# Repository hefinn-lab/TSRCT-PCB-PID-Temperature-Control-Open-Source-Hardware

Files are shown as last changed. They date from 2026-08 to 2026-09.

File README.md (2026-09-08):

# An Open-Source Dual-Channel RTD Thermal-Control Platform for Research-Scale PEM Water Electrolysis Balance-of-Plant Integration

**TSRCT-PCB-01** is an Arduino Nano Every–based temperature-control board for experimental thermal management. It connects two Pt100 or Pt1000 resistance temperature detectors (RTDs) to independent **5 V digital solid-state-relay (SSR) control outputs**, with controller power and host communication through a single USB connection. External SSRs switch a separately powered heater circuit.

**Repository release: v1.1.1 | Firmware and Python tools: V1.1**

[Setup and dependencies](DEPENDENCIES.md) · [Release notes](RELEASE-NOTES.md) · [Citation](CITATION.cff) · [Licensing](LICENSE.md)

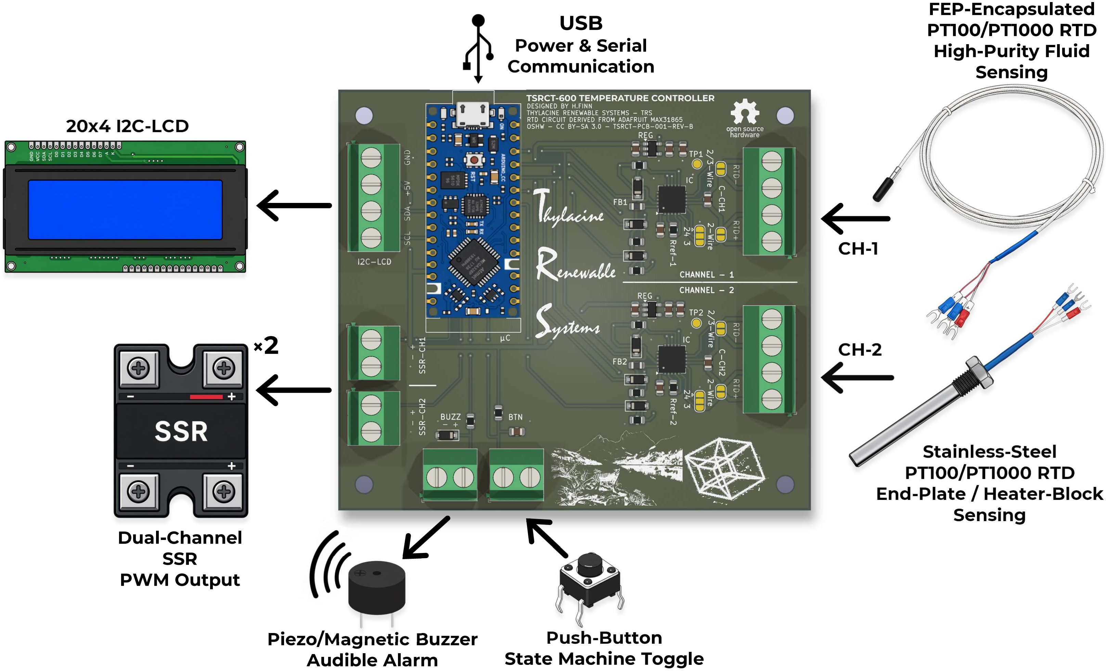
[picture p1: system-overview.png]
TSRCT-PCB-01 system overview showing dual RTD inputs, SSR outputs, USB communication and user-interface connections


The accompanying manuscript describes the circuit, analytical tuning methods, experimental results, and operating scope. The reported experiments characterise temperature control on isolated, dry electrolysis-cell end plates.

## Basic functions

- Two MAX31865 RTD acquisition channels with independent temperature set points.
- Pt100 or Pt1000 operation, with matching component population and firmware settings; configurable 2-, 3-, or 4-wire connections.
- PI/PID control, manual operation, set-point ramping, and anti-windup.
- Windowed SSR actuation, with nominal 1 s control and actuation windows.
- Open-loop step-response acquisition and FOPDT-based analytical SIMC PI / iSIMC PID tuning tools.
- USB serial telemetry and companion Python logging and analysis.
- RTD fault handling, stale-measurement detection, and over-temperature alarms that disable both heater commands.
- Connections for an I²C display, push button, and audible alarm.

## Adafruit design attribution and changes

**The RTD front ends are based on the Adafruit MAX31865 breakout design by Limor Fried/Ladyada for Adafruit Industries.** The MAX31865 interface software is derived from Adafruit's Arduino library. The original projects are:

- [Adafruit MAX31865 hardware: schematics and PCB files](https://github.com/adafruit/Adafruit-MAX31865-PCB)
- [Adafruit MAX31865 Arduino library](https://github.com/adafruit/Adafruit_MAX31865)

**Hardware changes:** TSRCT-PCB-01 integrates two RTD front ends into one control PCB with the Nano Every, SSR command connections, and display, button, and alarm interfaces. The layout consolidates the measurement and control wiring while retaining configurable RTD connections. Reference resistors and input-filter capacitors are populated for the selected sensor type.

**Firmware changes:** RTD acquisition has been changed to a **non-blocking state machine**. Bias settling, conversion waiting, and readout are scheduled as separate stages so acquisition does not hold up the main loop during the sensor waiting periods. The application adds independent control loops, timer-scheduled SSR windows, analytical tuning support, fault handling, and host telemetry. The V1.1 timer implementation uses the Nano Every's ATmega4809 TCB2 peripheral; another microcontroller requires timer adaptation.

## RTD wiring and soldering

Use the Adafruit learning guide for the underlying RTD connection principles and solder-jumper configuration:

- [MAX31865 guide: overview](https://learn.adafruit.com/adafruit-max31865-rtd-pt100-amplifier/)
- [Assembly and soldering guide](https://learn.adafruit.com/adafruit-max31865-rtd-pt100-amplifier/assembly)
- [RTD wiring and configuration: 2-, 3-, and 4-wire sensors](https://learn.adafruit.com/adafruit-max31865-rtd-pt100-amplifier/rtd-wiring-config)

These instructions illustrate the Adafruit breakout. Use the **TSRCT-PCB-01 schematic and PCB labels** to identify the corresponding terminals and jumpers before soldering or cutting a trace.

| Sensor | Nominal resistance at 0 °C | Reference resistor | RTD input-filter capacitor |
| --- | ---: | ---: | ---: |
| Pt100 | 100 Ω | 430 Ω | 100 nF |
| Pt1000 | 1000 Ω | 4.3 kΩ | 10 nF |

Set the firmware's nominal RTD resistance, reference-resistor value, and wiring mode to match each populated channel. Changing from Pt100 to Pt1000 requires matching hardware and software configuration. The V1.1 default configuration uses two three-wire Pt100 sensors with 430 Ω reference resistors.

## Getting started

1. Assemble the board using its schematic and bill of materials, then configure the RTD connections as above.
2. Follow [DEPENDENCIES.md](DEPENDENCIES.md) to configure the Arduino Nano Every target and Arduino megaAVR Boards core, install the Python packages, and select the matching sketch/logger pair.
3. Connect the RTDs and compatible SSR control inputs, checking input-current requirements against the board's output capability. Heater power must pass through the external switching circuit, with independent thermal protection.
4. Upload the nominal-control or analytical-tuning sketch and run its companion Python logger. Before enabling heater power, confirm plausible temperature readings, correct sensor-to-heater channel pairing, and heater-off behaviour on your assembled system.

The loggers record telemetry; closing a logger does not stop heating. Use the controller's local control/abort function. Repository documentation can receive a new release version while unchanged firmware and Python tools retain V1.1.

## Attribution and licensing

Hardware design files are licensed under **CC BY-SA 3.0**. Original TSRCT software contributions are licensed under **MIT**, and Adafruit-derived code retains its upstream notices. See [LICENSE.md](LICENSE.md) for the component-specific terms and [ADAFRUIT-NOTICES.md](ADAFRUIT-NOTICES.md) for attribution. Preserve the applicable notices when redistributing or modifying the design or software.

Please acknowledge the original Adafruit projects when reusing these RTD front ends or their interface code, and refer to the accompanying manuscript for the TSRCT-PCB-01 design and experimental methods.

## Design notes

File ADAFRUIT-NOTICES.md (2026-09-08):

# Adafruit attribution and upstream notices

## Hardware

The TSRCT-PCB-01 RTD front ends are adapted from the **Adafruit MAX31865 PCB**, designed by **Limor Fried/Ladyada for Adafruit Industries**.

- [Original hardware repository](https://github.com/adafruit/Adafruit-MAX31865-PCB)
- [Upstream CC BY-SA 3.0 licence](https://github.com/adafruit/Adafruit-MAX31865-PCB/blob/master/license.txt)
- [Assembly and wiring guide](https://learn.adafruit.com/adafruit-max31865-rtd-pt100-amplifier/)

Changes in TSRCT-PCB-01 include integrating two RTD front ends with an Arduino Nano Every, independent SSR command connections, and user-interface circuitry on one PCB. Hardware adaptations are distributed under CC BY-SA 3.0. See LICENSE-CC-BY-SA-3.0.txt for the legal text.

The following upstream README text is retained for attribution (its descriptions concern the original Adafruit breakout):

> Adafruit MAX31865 PCB
>
> Click here to purchase one from the Adafruit shop
>
> PCB files for the Adafruit MAX31865 RTD Sensor Breakout. Format is EagleCAD schematic and board layout
>
> https://www.adafruit.com/product/3328
>
> Description
>
> For precision temperature sensing, nothing beats a Platinum RTD. Resistance temperature detectors (RTDs) are temperature sensors that contain a resistor that changes resistance value as its temperature changes, basically a kind of thermistor. In this sensor, the resistor is actually a small strip of Platinum with a resistance of 100 ohms at 0°C, thus the name PT100.
>
> Compared to most NTC/PTC thermistors, the PT type of RTD is much most stable and precise (but also more expensive) PT100's have been used for many years to measure temperature in laboratory and industrial processes, and have developed a reputation for accuracy (better than thermocouples), repeatability, and stability.
>
> However, to get that precision and accuracy out of your PT100 RTD you must use an amplifier that is designed to read the low resistance. Better yet, have an amplifier that can automatically adjust and compensate for the resistance of the connecting wires. If you're looking for a great RTD sensor, today is your lucky day because we have a lovely Adafruit RTD Sensor Amplifier with the MAX31865 breakout for use with any 2, 3 or 4 wire PT100 RTD!
>
> License
>
> Adafruit invests time and resources providing this open source design, please support Adafruit and open-source hardware by purchasing products from Adafruit!
>
> Designed by Limor Fried/Ladyada for Adafruit Industries.
>
> Creative Commons Attribution/Share-Alike, all text above must be included in any redistribution. See license.txt for additional details.

## Software

The local MAX31865 interface and temperature-conversion routines in the V1.1 sketches are derived from the **Adafruit MAX31865 Arduino library**, written by **Limor Fried/Ladyada for Adafruit Industries**.

- [Original software repository](https://github.com/adafruit/Adafruit_MAX31865)
- [Source file carrying the upstream notice](https://github.com/adafruit/Adafruit_MAX31865/blob/master/Adafruit_MAX31865.cpp)

The upstream source banner is preserved below. Retain this banner in redistributed source files containing the derived driver:

```cpp
/***************************************************
  This is a library for the Adafruit PT100/P1000 RTD Sensor w/MAX31865

  Designed specifically to work with the Adafruit RTD Sensor
  ----> https://www.adafruit.com/products/3328

  This sensor uses SPI to communicate, 4 pins are required to
  interface

  Adafruit invests time and resources providing this open source code,
  please support Adafruit and open-source hardware by purchasing
  products from Adafruit!

  Written by Limor Fried/Ladyada for Adafruit Industries.
  BSD license, all text above must be included in any redistribution
 ****************************************************/
```

The upstream README also states:

> Adafruit MAX31865
>
> This is the Adafruit MAX31865 Arduino Library
>
> Tested and works great with the Adafruit Thermocouple Breakout w/MAX31865
>
> http://www.adafruit.com/products/3328
>
> These sensors use SPI to communicate, 4 pins are required to interface
>
> Adafruit invests time and resources providing this open source code, please support Adafruit and open-source hardware by purchasing products from Adafruit!
>
> Written by Limor Fried/Ladyada for Adafruit Industries.
>
> BSD license, check license.txt for more information All text above must be included in any redistribution

TSRCT modifications separate bias settling, conversion waiting, and readout into a non-blocking acquisition sequence, and integrate acquisition with dual-channel control, timer-based actuation, fault supervision, and telemetry. Original TSRCT contributions are MIT-licensed; the upstream portions retain the notices above.

The upstream software identifies its licence as **BSD** in the notices reproduced above. Preserve these notices, together with any additional licence text accompanying the incorporated source version. The MIT licence for original TSRCT contributions does not replace the upstream terms.

Adafruit is credited for its original contributions; this attribution does not imply endorsement of TSRCT-PCB-01.

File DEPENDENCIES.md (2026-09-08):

# Dependencies and running the V1.1 tools

This document describes the dependencies and execution instructions
for the V1.1 firmware and companion Python tools distributed with
repository release v1.1.1.

## Firmware

- Board: **Arduino Nano Every (ATmega4809)**, using **Arduino megaAVR Boards** in Boards Manager. A classic ATmega328P Nano is not compatible with the direct TCB2 timer implementation.
- LCD library: **LiquidCrystal_I2C**, using the Frank de Brabander **1.1.2 API** (`init()` and `backlight()`). Select the matching implementation; libraries sharing this header name can expose different APIs.
- `Arduino.h`, `Wire.h`, `SPI.h`, AVR interrupt/watchdog headers, and standard C headers come with the selected board toolchain.
- The modified MAX31865 driver is defined locally in both sketches. **No separate Adafruit_MAX31865, Adafruit BusIO, or PID library is required by these files.** Adafruit attribution remains required for the incorporated code.

## Matched files

| Task | Arduino sketch | Python companion |
| --- | --- | --- |
| Nominal control | `V1.1_TSRCT_PCB_Nominal_Dual_Channel.ino` | `V1.1_TSRCT_PCB_Nominal_Logger.py` |
| Open-loop identification and analytical tuning | `Analytical-Tuning-uC-Firmware-V1.1.ino` | `Analytical-Tuning-Logger.py` |

Use the filenames above when selecting the firmware and companion logger. Open each `.ino` in Arduino IDE and accept its prompt to create a matching sketch folder if needed. Upload only the sketch for the desired task. Before enabling heater power, check sensor configuration, channel pairing, and heater-off behaviour on the assembled system.

## Python

Use **Python 3.9 or newer**. From the repository root, create a virtual environment and install the dependencies:

```bash
python -m venv .venv
```

Activate it on Windows PowerShell:

```powershell
.venv\Scripts\Activate.ps1
```

Or on macOS/Linux:

```bash
source .venv/bin/activate
```

Then install:

```bash
python -m pip install -r requirements.txt
```

| Tool | External packages |
| --- | --- |
| Nominal logger | `pyserial`, `openpyxl` |
| Analytical logger | `pyserial`, `numpy`, `pandas`, `matplotlib`, `openpyxl`, `Pillow` |
| Optional analytical nonlinear fit | `scipy` |

Pillow is used by workbook image embedding. SciPy is optional; without it the primary crossing-based FOPDT identification and analytical tuning remain available.

```bash
python -m pip install -r requirements-optional.txt
```

To record the package versions used for your experiments:

```bash
python --version
python -m pip freeze > requirements-tested.txt
```

## Run

Close Arduino Serial Monitor and replace the example port with the board's port. Run from the directory containing the chosen logger, or supply its path.

```bash
python V1.1_TSRCT_PCB_Nominal_Logger.py --port COM4
python Analytical-Tuning-Logger.py --port COM5
```

On Linux, a port may be `/dev/ttyACM0`; on macOS, use the actual `/dev/cu.*` device.

Both pairs use **115200 baud**. The loggers are passive: they record and analyse telemetry rather than command heater shutdown. Closing a logger does not stop heating; use the board's local control/abort function.

For offline reconstruction:

```bash
python V1.1_TSRCT_PCB_Nominal_Logger.py --rebuild capture.csv
python Analytical-Tuning-Logger.py --rebuild capture.csv --controller isimc-pid
```

The analytical logger exports a selected channel's gains; apply the exported settings to the corresponding nominal-firmware channel. Default hardware settings in the V1.1 sketches are three-wire Pt100, 430 ohm reference conversion, and 50 Hz rejection.

Hardware design editing uses KiCad 10 as identified in the manuscript; KiCad is not needed to run the firmware or loggers.

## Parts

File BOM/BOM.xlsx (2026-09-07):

Qty | Digi-Key Part Number | Manufacturer Part Number | Manufacturer | Customer Reference | Designation | Footprint | Notes
1 |  | ABX00033 | Arduino | μC | Arduino Nano Every | Arduino Nano Every_Nano
2 | MAX31865ATP+-ND | MAX31865ATP+ | Analog Devices | U1, U4 (IC) | MAX31865 | Package_DFN_QFN:QFN-20-1EP_5x5mm_P0.65mm_EP3.1x3.1mm_ThermalVias | TQFN-20 5x5mm -- verified
2 | 576-2980-1-ND | MIC5225-3.3YM5-TR | Microchip | U2, U3 (REGULATOR) | MIC5225-3.3 | Package_TO_SOT_SMD:SOT-23-5 | SOT-23-5 -- verified
7 | 31-1N4148W-7-F-WCT-ND | 1N4148W-7-F-W | Diodes Inc. | D1–D7 | 1N4148 | Diode_SMD:D_SOD-123 | SOD-123 verified (NOT SOD-323). -W variant in stock
2 | 490-1054-1-ND | BLM21PG221SN1D | Murata | FB1, FB2 | Ferrite 220Ω @ 100MHz | Inductor_SMD:L_0805_2012Metric | 0805 verified
VAR. | P430DACT-ND | ERA-6AEB431V | Panasonic | Rref - PT100 channels | 430Ω 0.1% thin-film | Resistor_SMD:R_0805_2012Metric | 0805 verified - Rref for PT100 channels. Populate one per PT100 channel
VAR. | P4.3KDACT-ND | ERA-6AEB432V | Panasonic | Rref - PT1000 channel | 4.3kΩ 0.1% thin-film | Resistor_SMD:R_0805_2012Metric | 0805 verified - Rref for Pt1000 channels. Populate one per PT1000 channel
7 | 311-10.0KCRCT-ND | RC0805FR-0710KL | Yageo | R2, R3, R4, R6, R7, R8, R9 | 10K 1% | Resistor_SMD:R_0805_2012Metric | 0805 verified
1 | 311-220CRCT-ND | RC0805FR-07220RL | Yageo | R10 | 220Ω 1% | Resistor_SMD:R_0805_2012Metric | 0805 verified
4 | 1276-1003-1-ND | CL21B104KBCNNNC | Samsung | C1, C2, C8, C9 | 0.1uF X7R 50V | Capacitor_SMD:C_0805_2012Metric | 0805 verified. Combined: 8× decoupling
VAR. | 1276-1003-1-ND | CL21B104KBCNNNC | Samsung | C-CH1/CH-2 for PT100 - 1x per channel | 0.1uF X7R 50V | Capacitor_SMD:C_0805_2012Metric | PT100 channel filter. Placed as C-CH1/C-CH2. Populate one per PT100 channel
4 | 1276-6454-1-ND | CL21A106KAYNNNG | Samsung | C4, C5, C11, C13 | 10uF X5R 25V | Capacitor_SMD:C_0805_2012Metric | 0805 verified. G-variant of original E-variant (out of stock); identical electrical spec.
1 | 1276-1029-1-ND | CL21B105KBFNNNE | Samsung | C6 | 1uF X7R 50V | Capacitor_SMD:C_0805_2012Metric | 0805 verified. Button debounce.
VAR. | 1276-1015-1-ND | CL21B103KBANNNC | Samsung | C-CH1/CH-2 for PT1000 - 1x per channel | 10nF X7R 50V | Capacitor_SMD:C_0805_2012Metric | PT1000 channel filter. Placed as C-CH1/C-CH2. Populate one per PT1000 channel
3 | 277-1265-ND | 1715747 | Phoenix Contact | J6, J7, I2C-LCD | Screw_Terminal_01x04 5.08mm | TerminalBlock_Phoenix:TerminalBlock_Phoenix_MKDS-1,5-4-5.08_1x04_P5.08mm_Horizontal | MKDS 1,5/4-5,08 — 4-pos 5.08mm verified
4 | 277-1263-ND | 1715721 | Phoenix Contact | SSR-CH1, SSR-CH2, BTN, BUZZ | Screw_Terminal_01x02 5.08mm | TerminalBlock_Phoenix:TerminalBlock_Phoenix_MKDS-1,5-2-5.08_1x02_P5.08mm_Horizontal | Out of stock -- alternative option fine otherwise order from Mouser with split order fine?
 | BOM Note: All quantities are for one assembled TSRCT-PCB-001 PCB unless otherwise stated. Red rows are RTD-configuration-dependent components; populate the appropriate values for the selected PT100/PT1000 channel configuration.

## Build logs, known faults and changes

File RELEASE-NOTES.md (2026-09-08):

# TSRCT-PCB-01 v1.1.1

Public release of TSRCT-PCB-01, an open-source dual-channel Pt100/Pt1000 PID temperature-control platform for Arduino Nano Every, developed for research-scale PEM water electrolysis thermal management.

Repository release **v1.1.1** packages firmware and companion Python tools **V1.1**.

This release brings together:

- Hardware design and fabrication files, bill of materials, and assembly documentation.
- Dual-channel nominal-control firmware with non-blocking MAX31865 acquisition, 5 V SSR commands, PI/PID control, and fault handling.
- Open-loop step-identification firmware and Python tools for FOPDT identification and SIMC PI / iSIMC PID tuning.
- Python serial logging with CSV and XLSX output.
- Dependency instructions, citation metadata, and component-specific licensing and Adafruit attribution.

The RTD front ends are adapted from Adafruit's MAX31865 hardware design. The incorporated Adafruit-derived interface code has been restructured for non-blocking acquisition.

Hardware: CC BY-SA 3.0. Original software: MIT. Adafruit-derived software retains its upstream BSD notice; see [LICENSE.md](LICENSE.md) and [ADAFRUIT-NOTICES.md](ADAFRUIT-NOTICES.md).

See [DEPENDENCIES.md](DEPENDENCIES.md) for the supported board, matched firmware/logger pairs, and setup. The accompanying manuscript describes the experimental performance on isolated, dry end plates. Before enabling heating, adopters should confirm operation on their assembled hardware using the checks in the [README](README.md).

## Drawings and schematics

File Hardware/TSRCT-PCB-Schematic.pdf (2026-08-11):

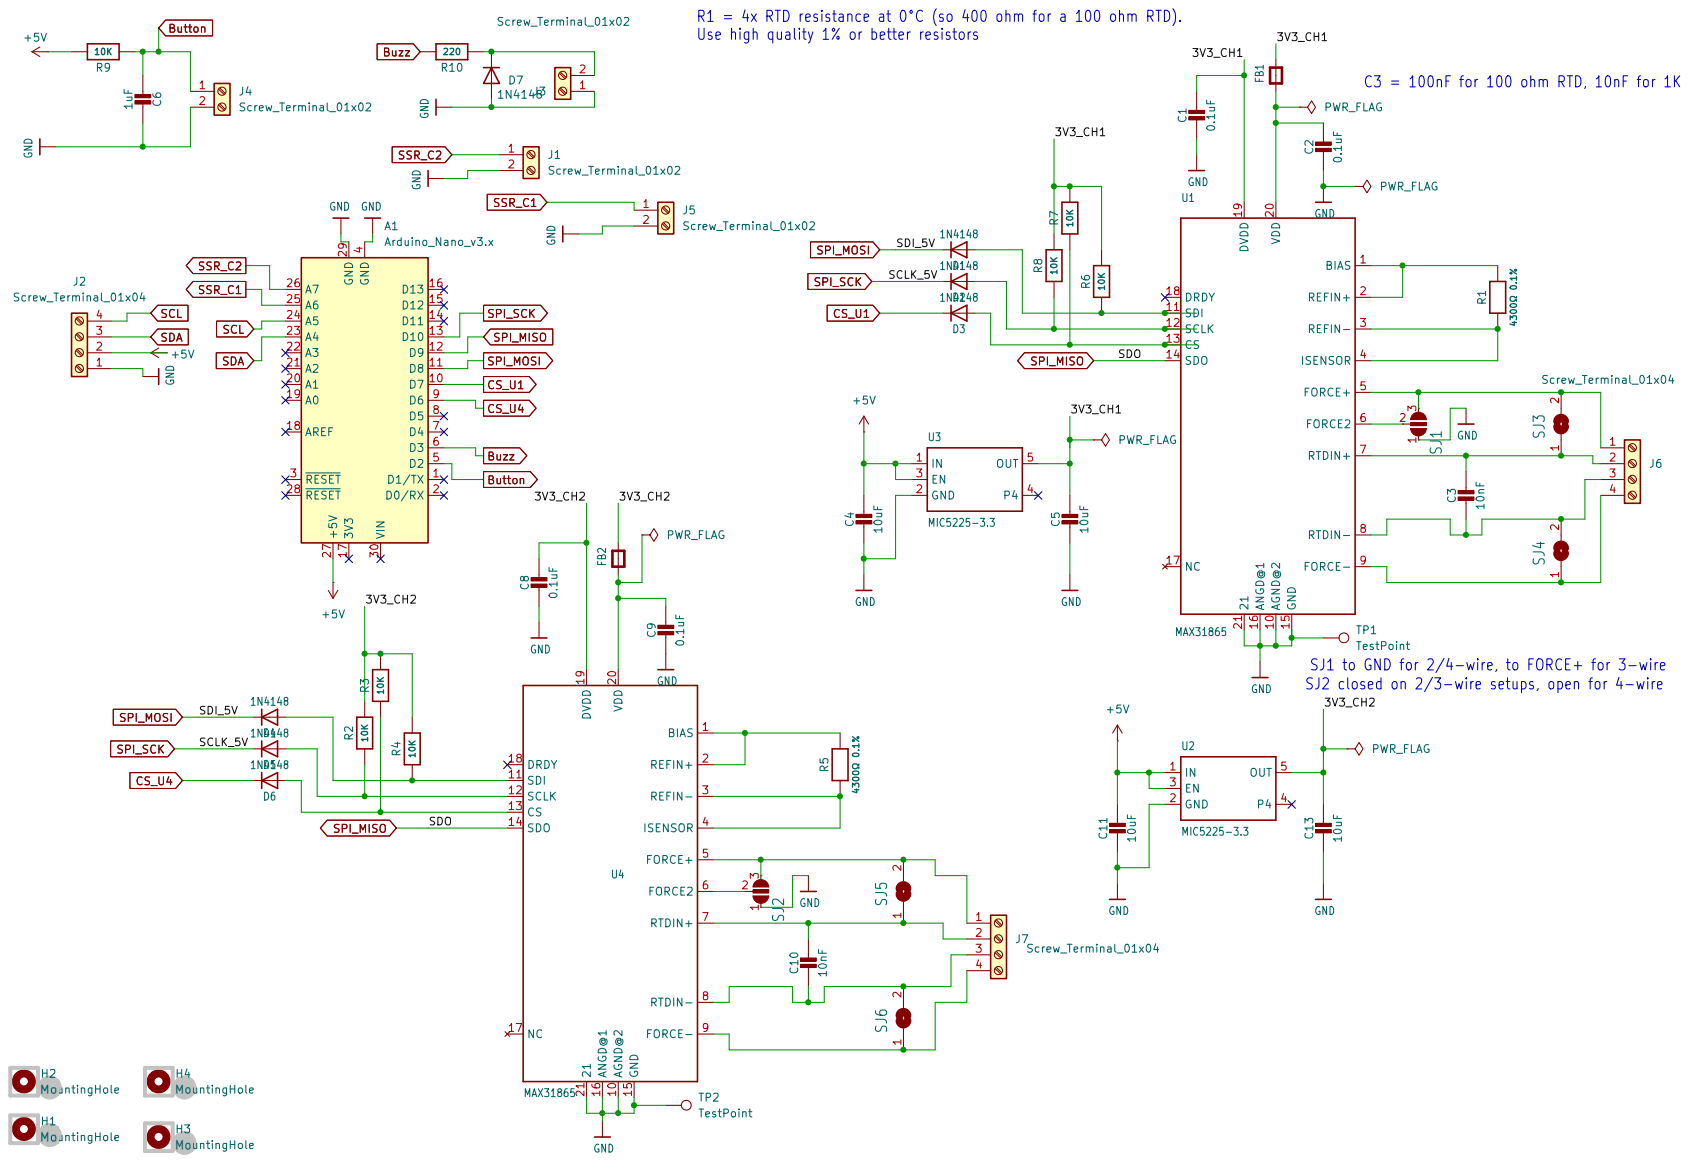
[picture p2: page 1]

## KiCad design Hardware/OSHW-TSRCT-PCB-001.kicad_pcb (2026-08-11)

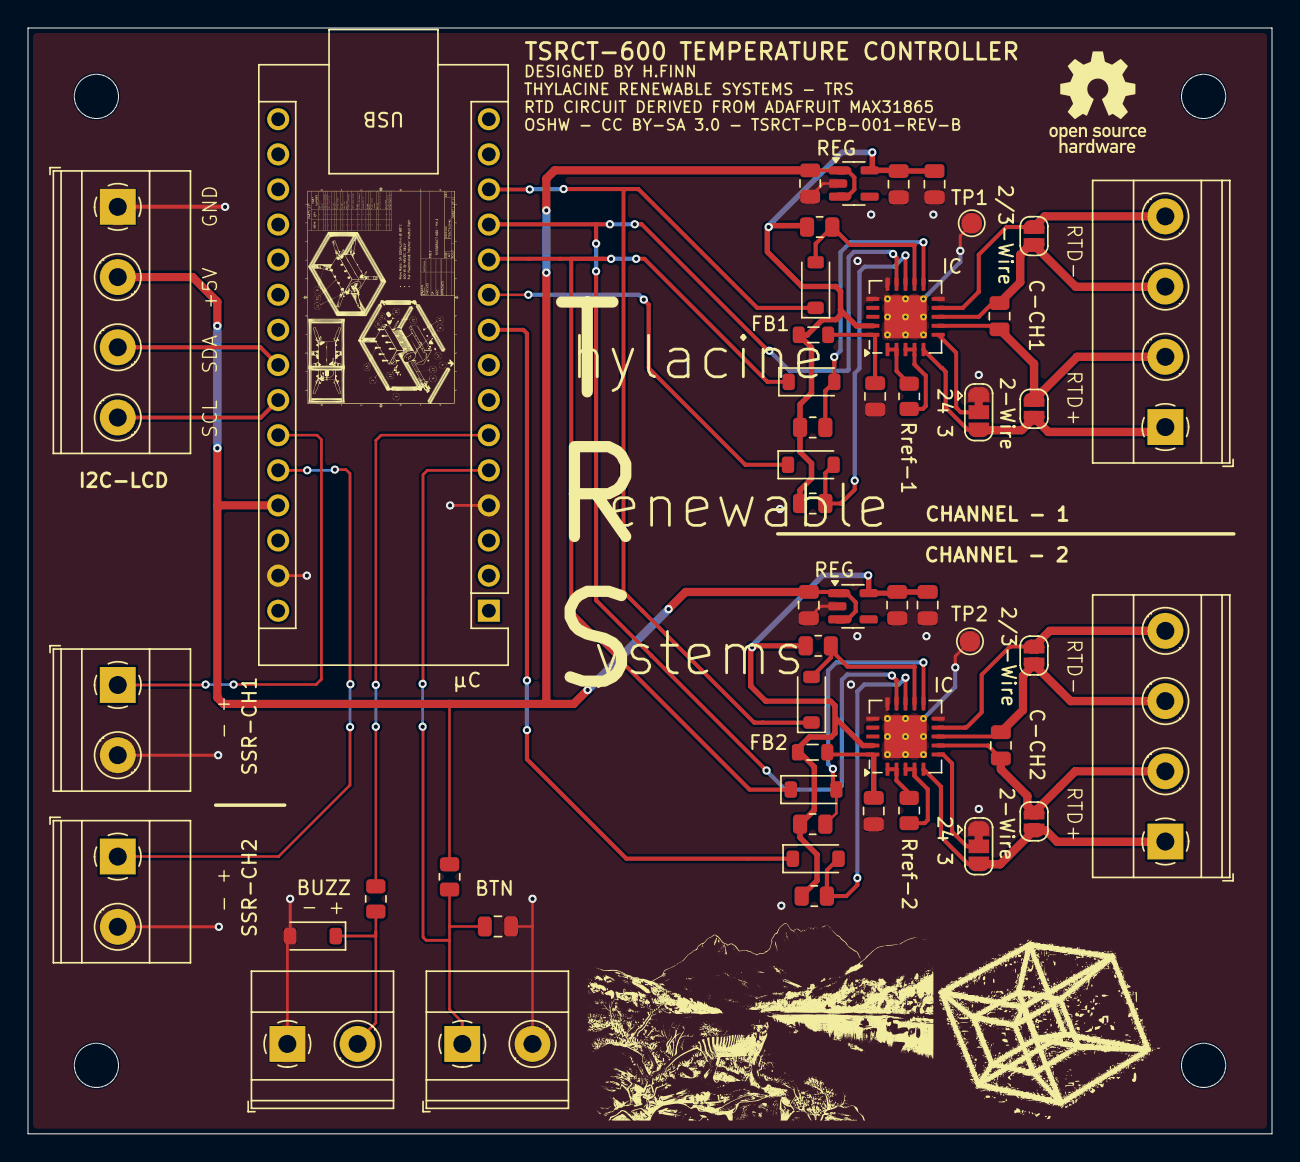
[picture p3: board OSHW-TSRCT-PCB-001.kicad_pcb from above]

Board: 2 copper layers, 90.0 x 80.0 mm, 54 parts (0 on the bottom side), 38 nets.

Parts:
2-Wire, 2-Wire#2, 2/3-Wire, 2/3-Wire#2: SOLDERJUMPER; SolderJumper-2_P1.3mm_Open_RoundedPad1.0x1.5mm
24 3, 24 3#2: SOLDERJUMPER_2WAY; SolderJumper-3_P1.3mm_Bridged12_RoundedPad1.0x1.5mm
BTN: Screw_Terminal_01x02; TerminalBlock_Phoenix_MKDS-1,5-2-5.08_1x02_P5.08mm_Horizont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
BUZZ: Screw_Terminal_01x02; TerminalBlock_Phoenix_MKDS-1,5-2-5.08_1x02_P5.08mm_Horizont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
C1, C2, C8, C9: 0.1uF; C_0805_2012Metric
C4, C5, C11, C13: 10uF; C_0805_2012Metric
C6: 1uF; C_0805_2012Metric
C-CH1, C-CH2: 10nF; C_0805_2012Metric
D1, D2, D3, D4, D5, D6, D7: 1N4148; D_SOD-123
FB1, FB2: FERRITE-0805NO; L_0805_2012Metric
H1, H2, H3, H4: MountingHole; MountingHole_3.2mm_M3
I2C-LCD: Screw_Terminal_01x04; TerminalBlock_Phoenix_MKDS-1,5-4-5.08_1x04_P5.08mm_Horizont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
IC: MAX31865; TQFN-20-1EP_5x5mm_P0.65mm_EP3.1x3.1mm_ThermalVias
IC#2: MAX31865; TQFN-20-1EP_5x5mm_P0.65mm_EP3.1x3.1mm_ThermalVias
J6, J7: Screw_Terminal_01x04; TerminalBlock_Phoenix_MKDS-1,5-4-5.08_1x04_P5.08mm_Horizont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
R2, R3, R4, R6, R7, R8, R9: 10K; R_0805_2012Metric
R10: 220; R_0805_2012Metric
REG: MIC5225-3.3; SOT-23-5
REG#2: MIC5225-3.3; SOT-23-5
Rref-1, Rref-2: 4300Ω 0.1%; R_0805_2012Metric
SSR-CH1, SSR-CH2: Screw_Terminal_01x02; TerminalBlock_Phoenix_MKDS-1,5-2-5.08_1x02_P5.08mm_Horizont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
TP1, TP2: TestPoint; TestPoint_Pad_D1.5mm
μC: Arduino_Nano_v3.x; Arduino_Nano

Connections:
+5V: C4.1, C11.1, I2C-LCD.2, R9.2, REG.1 (IN), REG.3 (EN), REG#2.1 (IN), REG#2.3 (EN), μC.27 (+5V)
/3V3_CH1: C1.1, C5.1, FB1.2, IC#2.19 (DVDD), R6.2, R7.2, R8.2, REG.5 (OUT)
/3V3_CH2: C8.1, C13.1, FB2.2, IC.19 (DVDD), R2.2, R3.2, R4.2, REG#2.5 (OUT)
Button: BTN.1, C6.2, R9.1, μC.5 (D2)
Buzz: R10.2, μC.6 (D3)
CS_U1: D3.1, μC.10 (D7)
CS_U4: D6.1, μC.9 (D6)
GND: 24 3.1, 24 3#2.1, BTN.2, BUZZ.1, C1.2, C2.2, C4.2, C5.2, C6.1, C8.2, C9.2, C11.2, C13.2, D7.2 (A), I2C-LCD.1, IC.10 (AGND@2), IC.15 (GND), IC.16 (ANGD@1), IC.21, IC#2.10 (AGND@2), IC#2.15 (GND), IC#2.16 (ANGD@1), IC#2.21, REG.2 (GND), REG#2.2 (GND), SSR-CH1.2, SSR-CH2.2, TP1.1 (1_1), TP2.1 (1_1), μC.4 (GND), μC.29 (GND)
unnamed: BUZZ.2, D7.1 (K), R10.1
unnamed: C2.1, FB1.1, IC#2.20 (VDD)
unnamed: C9.1, FB2.1, IC.20 (VDD)
unnamed: 2-Wire#2.2, 24 3.3, IC#2.5 (FORCE+), J6.1
unnamed: 2-Wire#2.1, C-CH1.1, IC#2.7 (RTDIN+), J6.2
unnamed: 2/3-Wire.2, C-CH1.2, IC#2.8 (RTDIN-), J6.3
unnamed: 2/3-Wire.1, IC#2.9 (FORCE-), J6.4
unnamed: 2-Wire.2, 24 3#2.3, IC.5 (FORCE+), J7.1
unnamed: 2-Wire.1, C-CH2.1, IC.7 (RTDIN+), J7.2
unnamed: 2/3-Wire#2.2, C-CH2.2, IC.8 (RTDIN-), J7.3
unnamed: 2/3-Wire#2.1, IC.9 (FORCE-), J7.4
unnamed: IC#2.1 (BIAS), IC#2.2 (REFIN+), Rref-1.2
unnamed: D3.2, IC#2.13 (CS), R7.1
unnamed: 24 3.2, IC#2.6 (FORCE2)
unnamed: IC#2.3 (REFIN-), IC#2.4 (ISENSOR), Rref-1.1
unnamed: D2.2, IC#2.12 (SCLK), R8.1
unnamed: D1.2, IC#2.11 (SDI), R6.1
unnamed: IC.1 (BIAS), IC.2 (REFIN+), Rref-2.2
unnamed: D6.2, IC.13 (CS), R3.1
unnamed: 24 3#2.2, IC.6 (FORCE2)
unnamed: IC.3 (REFIN-), IC.4 (ISENSOR), Rref-2.1
unnamed: D5.2, IC.12 (SCLK), R2.1
unnamed: D4.2, IC.11 (SDI), R4.1
SCL: I2C-LCD.4, μC.24 (A5)
SDA: I2C-LCD.3, μC.23 (A4)
SPI_MISO: IC.14 (SDO), IC#2.14 (SDO), μC.12 (D9)
SPI_MOSI: D1.1, D4.1, μC.11 (D8)
SPI_SCK: D2.1, D5.1, μC.13 (D10)
SSR_C1: SSR-CH1.1, μC.25 (A6)
SSR_C2: SSR-CH2.1, μC.26 (A7)

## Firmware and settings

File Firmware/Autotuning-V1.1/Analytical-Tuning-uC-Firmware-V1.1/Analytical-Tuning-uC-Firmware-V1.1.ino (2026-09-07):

// Analytical-Tuning-uC-Firmware-V1.1.ino
// TSRCT-PCB-01 Rev B / Arduino Nano Every (ATmega4809), 115200 baud.
// Companion: Analyitical-Tuning-Logger.py (V1.1 internally).
// Save in folder Analytical-Tuning-uC-Firmware-V1.1; select Nano Every.
// Dependency: LiquidCrystal_I2C with init()/backlight() API.
// Based on the supplied TSRCT_PCB_StepID_Autotune_v2 firmware; driver shared
// with nominal V1.1, derived from Adafruit MAX31865 (BSD licence).
//
// Button: IDLE -> qualified 0% baseline -> fixed open-loop heater step.
// During baseline/step: press to ABORT. After completion: press returns to IDLE.
// ALARM: repair fault/cool required sensors, then press to acknowledge to IDLE.
// Heating never restarts automatically. Only the selected channel actuates.
// The PC logger is passive and computes FOPDT / SIMC PI / iSIMC PID afterwards.
// Closing Python does not stop the heater test; use the local button to abort.
// A series thermal fuse is independent protection against a stuck-on SSR.
//
// V1.1: Pt100/430 ohm, channel selection, validated rounded step duty, recent
// baseline window, boundary timestamp, ISR duration/heartbeat cutoffs, watchdog,
// sensor requalification, repeated terminal telemetry and CRC16 framing.
// EXPERIMENTAL TEST-BENCH CHECKS PASSED
#include <Arduino.h>
#if !defined(__AVR_ATmega4809__)
#error "Select Arduino Nano Every (ATmega4809), not classic Nano."
#endif
#include <Wire.h>
#include <LiquidCrystal_I2C.h>
#include <math.h>
#include <string.h>
#include <avr/interrupt.h>
#include <avr/wdt.h>
#include <util/atomic.h>

#define MAX31865_CONFIG_REG       0x00
#define MAX31865_CONFIG_BIAS      0x80
#define MAX31865_CONFIG_MODEAUTO  0x40
#define MAX31865_CONFIG_1SHOT     0x20
#define MAX31865_CONFIG_3WIRE     0x10
#define MAX31865_CONFIG_FAULTSTAT 0x02
#define MAX31865_CONFIG_FILT50HZ  0x01
#define MAX31865_RTDMSB_REG       0x01
#define MAX31865_HFAULTMSB_REG    0x03
#define MAX31865_HFAULTLSB_REG    0x04
#define MAX31865_LFAULTMSB_REG    0x05
#define MAX31865_LFAULTLSB_REG    0x06
#define MAX31865_FAULTSTAT_REG    0x07
#define RTD_A 3.9083e-3
#define RTD_B -5.775e-7

typedef enum max31865_numwires {
  MAX31865_2WIRE = 0, MAX31865_3WIRE = 1, MAX31865_4WIRE = 0
} max31865_numwires_t;

class LocalMAX31865 {
 public:
  LocalMAX31865(uint8_t cs, uint8_t mosi, uint8_t miso, uint8_t sck)
      : csPin(cs), mosiPin(mosi), misoPin(miso), sckPin(sck) {}

  bool begin(max31865_numwires_t wires, bool filter50Hz) {
    pinMode(csPin, OUTPUT);
    pinMode(mosiPin, OUTPUT);
    pinMode(misoPin, INPUT);
    pinMode(sckPin, OUTPUT);
    digitalWrite(csPin, HIGH);
    digitalWrite(sckPin, LOW);
    digitalWrite(mosiPin, LOW);

    uint8_t cfg = readRegister8(MAX31865_CONFIG_REG);
    cfg &= ~(MAX31865_CONFIG_BIAS | MAX31865_CONFIG_MODEAUTO |
             MAX31865_CONFIG_1SHOT | MAX31865_CONFIG_FILT50HZ);
    if (wires == MAX31865_3WIRE) cfg |= MAX31865_CONFIG_3WIRE;
    else cfg &= ~MAX31865_CONFIG_3WIRE;
    if (filter50Hz) cfg |= MAX31865_CONFIG_FILT50HZ;
    expectedConfig = cfg & (MAX31865_CONFIG_MODEAUTO | MAX31865_CONFIG_3WIRE |
                            MAX31865_CONFIG_FILT50HZ);
    writeRegister8(MAX31865_CONFIG_REG, cfg);
    setThresholds(0, 0xFFFF);
    clearFault();
    return configurationMatches();
  }

  bool configurationMatches() {
    const uint8_t mask = MAX31865_CONFIG_MODEAUTO | MAX31865_CONFIG_3WIRE |
                         MAX31865_CONFIG_FILT50HZ;
    return (readConfig() & mask) == expectedConfig;
  }

  uint8_t readFault() {
    return readRegister8(MAX31865_FAULTSTAT_REG);
  }

  void clearFault() {
    uint8_t c = readRegister8(MAX31865_CONFIG_REG);
    c &= ~0x2C;
    c |= MAX31865_CONFIG_FAULTSTAT;
    writeRegister8(MAX31865_CONFIG_REG, c);
  }

  void enableBias(bool enabled) {
    uint8_t c = readRegister8(MAX31865_CONFIG_REG);
    if (enabled) c |= MAX31865_CONFIG_BIAS;
    else c &= ~MAX31865_CONFIG_BIAS;
    writeRegister8(MAX31865_CONFIG_REG, c);
  }

  void triggerOneShot() {
    uint8_t c = readRegister8(MAX31865_CONFIG_REG);
    c |= MAX31865_CONFIG_1SHOT;
    writeRegister8(MAX31865_CONFIG_REG, c);
  }

  uint16_t readRawRTD(bool &faultPresent, uint8_t &faultCode) {
    uint16_t r = readRegister16(MAX31865_RTDMSB_REG);
    faultCode = readFault();
    faultPresent = ((r & 1U) != 0U) || (faultCode != 0U);
    return r >> 1;
  }

  float calculateTemperature(uint16_t raw, float nominal, float ref) {
    float Z1, Z2, Z3, Z4, Rt, temp;
    Rt = raw;
    Rt /= 32768.0f;
    Rt *= ref;
    Z1 = -RTD_A;
    Z2 = RTD_A * RTD_A - (4.0f * RTD_B);
    Z3 = (4.0f * RTD_B) / nominal;
    Z4 = 2.0f * RTD_B;
    temp = Z2 + (Z3 * Rt);
    temp = (sqrt(temp) + Z1) / Z4;
    if (temp >= 0.0f) return temp;

    Rt /= nominal;
    Rt *= 100.0f;
    float p = Rt;
    temp = -242.02f;
    temp += 2.2228f * p;
    p *= Rt; temp += 2.5859e-3f * p;
    p *= Rt; temp -= 4.8260e-6f * p;
    p *= Rt; temp -= 2.8183e-8f * p;
    p *= Rt; temp += 1.5243e-10f * p;
    return temp;
  }

  uint8_t readConfig() {
    return readRegister8(MAX31865_CONFIG_REG);
  }

 private:
  uint8_t csPin, mosiPin, misoPin, sckPin;
  uint8_t expectedConfig = 0;

  uint8_t transfer8(uint8_t out) {
    uint8_t in = 0;
    for (uint8_t m = 0x80; m; m >>= 1) {
      digitalWrite(mosiPin, (out & m) ? HIGH : LOW);
      digitalWrite(sckPin, HIGH);
      delayMicroseconds(1);
      digitalWrite(sckPin, LOW);
      if (digitalRead(misoPin)) in |= m;
      delayMicroseconds(1);
    }
    return in;
  }

  uint8_t readRegister8(uint8_t a) {
    digitalWrite(csPin, LOW);
    transfer8(a & 0x7F);
    uint8_t v = transfer8(0xFF);
    digitalWrite(csPin, HIGH);
    return v;
  }

  uint16_t readRegister16(uint8_t a) {
    digitalWrite(csPin, LOW);
    transfer8(a & 0x7F);
    uint16_t v = (uint16_t)transfer8(0xFF) << 8;
    v |= transfer8(0xFF);
    digitalWrite(csPin, HIGH);
    return v;
  }

  void writeRegister8(uint8_t a, uint8_t v) {
    digitalWrite(csPin, LOW);
    transfer8(a | 0x80);
    transfer8(v);
    digitalWrite(csPin, HIGH);
  }

  void setThresholds(uint16_t l, uint16_t u) {
    writeRegister8(MAX31865_LFAULTLSB_REG, l & 0xFF);
    writeRegister8(MAX31865_LFAULTMSB_REG, l >> 8);
    writeRegister8(MAX31865_HFAULTLSB_REG, u & 0xFF);
    writeRegister8(MAX31865_HFAULTMSB_REG, u >> 8);
  }
};


// ============================================================================
// USER SETTINGS -- flash one selected heater/sensor pair per identification run.
// ============================================================================
const uint8_t TEST_CHANNEL = 1;        // 1 = RTD1/CS7 -> A6; 2 = RTD2/CS6 -> A7
const bool MONITOR_OTHER_CHANNEL = true; // false permits a single-sensor installation
const float R_REF = 430.0f;            // both physical reference resistors: 430 ohm
const float RNOMINAL = 100.0f;         // both probes: Pt100
const uint8_t RTD_WIRE_COUNT = 3;      // match the physical 2/3/4-wire connection
const bool RTD_FILTER_50HZ = true;     // Australian mains; false selects 60 Hz
const float STEP_DUTY_PERCENT = 15.0f;
const uint32_t RUN_DURATION_MS = 3UL * 60UL * 60UL * 1000UL;
const uint32_t BASELINE_MIN_DURATION_MS = 120000UL;
const uint32_t BASELINE_MAX_DURATION_MS = 600000UL;
const uint8_t BASELINE_WINDOW_SAMPLES = 60;
const float BASELINE_MAX_P2P_C = 0.20f;
const float CH1_OVERTEMP_C = 85.0f;
const float CH2_OVERTEMP_C = 85.0f;

// ADVANCED SETTINGS
const uint16_t PWM_WINDOW_MS = 1000U;
const uint32_t RTD_BIAS_SETTLE_US = 10000UL;
const uint32_t RTD_CONVERSION_US = 70000UL; // >66 ms maximum for 50 Hz conversion
const uint32_t RTD_SAMPLE_INTERVAL_MS = 160UL;
const uint32_t RTD_STALE_TIMEOUT_MS = 1000UL;
const float RTD_MIN_C = -20.0f, RTD_MAX_C = 200.0f, MAX_RTD_STEP_C = 2.0f;
const uint8_t MAX_CONSECUTIVE_RTD_FAILURES = 5, RTD_RECOVERY_SAMPLES = 5;
const float ALARM_RESET_HYSTERESIS_C = 2.0f;
const uint16_t SSR_COMMAND_TIMEOUT_MS = 2500U;
const uint32_t SERIAL_LOG_INTERVAL_MS = 1000UL, HEADER_INTERVAL_MS = 30000UL;
const uint8_t TEST_INDEX = TEST_CHANNEL == 2 ? 1 : 0;
const max31865_numwires_t RTD_WIRES = RTD_WIRE_COUNT == 3 ? MAX31865_3WIRE : MAX31865_2WIRE;

const uint8_t buttonPin=2, buzzerPin=3, RTD1_CS_PIN=7, RTD2_CS_PIN=6;
const uint8_t SPI_MOSI_PIN=8, SPI_MISO_PIN=9, SPI_SCK_PIN=10;
const uint8_t ssrPin_C1=A6, ssrPin_C2=A7;
LiquidCrystal_I2C lcd(0x27,20,4);
LocalMAX31865 rtd1(RTD1_CS_PIN,SPI_MOSI_PIN,SPI_MISO_PIN,SPI_SCK_PIN);
LocalMAX31865 rtd2(RTD2_CS_PIN,SPI_MOSI_PIN,SPI_MISO_PIN,SPI_SCK_PIN);

enum SystemState : uint8_t {
  STATE_IDLE=0, STATE_BASELINE=1, STATE_STEP_RUNNING=2,
  STATE_ALARM=3, STATE_COMPLETE=4, STATE_ABORTED=5
};
enum FaultFlags : uint16_t {
  FAULT_NONE=0, FAULT_CH1_OVERTEMP=0x0001, FAULT_CH2_OVERTEMP=0x0002,
  FAULT_CH1_RTD=0x0004, FAULT_CH2_RTD=0x0008, FAULT_RTD_STALE=0x0010,
  FAULT_CONFIGURATION=0x0020, FAULT_COMMAND_TIMEOUT=0x0040,
  FAULT_WATCHDOG_RESET=0x0080
};
SystemState systemState=STATE_IDLE;
uint16_t faultFlagsLatched=0;
uint16_t stepOnMs=0; // calculated only after configuration validation
float appliedDutyPct=0;
uint8_t resetCause=0;

float tempRtd[2]={NAN,NAN}, lastValidRtd[2]={NAN,NAN};
float recoveryCandidateC[2]={NAN,NAN};
uint8_t recoveryCount[2]={0,0}, rtdFailureCount[2]={0,0}, rtdFaultCode[2]={0,0};
bool qualifiedOvertemp[2]={false,false};
uint32_t lastRtdSampleMillis[2]={0,0}, rtdSampleCount[2]={0,0};
uint8_t rtdState=0;
uint32_t rtdStateStartUs=0, rtdCycleStartMillis=0;

volatile bool ssrTimerEnabled=false, ssrCommandTimeout=false;
volatile uint16_t ssrCommandAgeMs=0, ssrWindowTickMs=0;
volatile bool ssrPhysicalState[2]={false,false};
volatile uint16_t ssrPendingOnMs[2]={0,0}, ssrActiveOnMs[2]={0,0};
volatile uint16_t ssrHighTicksCurrent[2]={0,0}, ssrHighTicksLast[2]={0,0};
volatile uint16_t ssrCommandMsLast[2]={0,0};
volatile uint32_t ssrWindowSequence=0, ssrCompletedWindowSequence=0;
volatile bool stepLatchRequested=false, ssrStepApplied=false, ssrRunComplete=false;
volatile uint32_t ssrStepStartMillis=0, ssrStepStartSequence=0, ssrStepElapsedMs=0;
uint32_t completedWindowSequence=0;
uint16_t completedCommandMs=0;
uint32_t scheduledHighUs=0;
float scheduledDutyPct=0;

uint32_t experimentStartMillis=0, stepStartMillis=0, terminalMillis=0;
uint32_t stepStartWindowSequence=0, runId=0, telemetrySequence=0;
bool stepCommandArmed=false, forceLog=true;
uint32_t lastBaselineSampleMillis=0, lastLogMillis=0, lastHeaderMillis=0;
uint32_t lastLcdMillis=0, lastHeartbeatMillis=0, lastAlarmBeepMillis=0;
uint32_t lastLoopStartUs=0, loopMaxUs=0;
bool alarmBuzzerOn=false;
float baselineSamples[BASELINE_WINDOW_SAMPLES];
uint8_t baselineIndex=0, baselineCount=0;
float baselineMeanC=NAN, baselineP2PC=NAN;
int buttonState=HIGH, lastButtonReading=HIGH;
uint32_t lastDebounceTime=0;

// Explicit prototypes keep Arduino's sketch preprocessor independent of custom types.
bool validateConfiguration();
bool channelRequired(uint8_t);
float overtempThreshold(uint8_t);
bool rtdFresh(uint8_t);
void resetBaselineWindow();
void acceptRtdSample(uint8_t,float);
float validateAsyncTemperature(LocalMAX31865&,uint16_t,bool,uint8_t);
void serviceRTDAcquisition();
void configureSsrHardwareTimer();
void startSsrHardwareWindows();
void stopSsrHardwareWindows();
void snapshotCompletedSsrWindow();
uint16_t safetyFaults(bool);
void enterAlarm(uint16_t,const __FlashStringHelper*);
void evaluateSafety();
bool beginBaseline();
void abortRun(const __FlashStringHelper*);
void serviceBaselineQualification();
void serviceStepActivation();
bool acknowledgeAlarmIfSafe();
bool checkButtonPress();
void emitHeader();
void logSerial();
void updateLCD();
void printValue(Print&,float,uint8_t);
const char* stateName(uint8_t);

bool validateConfiguration() {
  if (TEST_CHANNEL < 1 || TEST_CHANNEL > 2 || RTD_WIRE_COUNT < 2 || RTD_WIRE_COUNT > 4) return false;
  if (!isfinite(R_REF) || !isfinite(RNOMINAL) || RNOMINAL <= 0 || R_REF <= RNOMINAL) return false;
  if (!isfinite(STEP_DUTY_PERCENT) || STEP_DUTY_PERCENT <= 0 || STEP_DUTY_PERCENT > 100) return false;
  if (STEP_DUTY_PERCENT * PWM_WINDOW_MS / 100.0f < 0.5f) return false;
  if (RUN_DURATION_MS < 1000UL || RUN_DURATION_MS > 86400000UL) return false;
  if (BASELINE_MIN_DURATION_MS < (uint32_t)BASELINE_WINDOW_SAMPLES * 1000UL ||
      BASELINE_MAX_DURATION_MS <= BASELINE_MIN_DURATION_MS || BASELINE_MAX_DURATION_MS > 3600000UL) return false;
  if (!isfinite(BASELINE_MAX_P2P_C) || BASELINE_MAX_P2P_C <= 0) return false;
  if (!isfinite(CH1_OVERTEMP_C) || !isfinite(CH2_OVERTEMP_C) ||
      CH1_OVERTEMP_C <= RTD_MIN_C || CH2_OVERTEMP_C <= RTD_MIN_C ||
      CH1_OVERTEMP_C > RTD_MAX_C || CH2_OVERTEMP_C > RTD_MAX_C) return false;
  return RTD_CONVERSION_US >= (RTD_FILTER_50HZ ? 66000UL : 55000UL);
}

bool channelRequired(uint8_t ch) { return ch == TEST_INDEX || MONITOR_OTHER_CHANNEL; }
float overtempThreshold(uint8_t ch) { return ch == 0 ? CH1_OVERTEMP_C : CH2_OVERTEMP_C; }
bool rtdFresh(uint8_t ch) {
  return lastRtdSampleMillis[ch] != 0 &&
      (uint32_t)(millis()-lastRtdSampleMillis[ch]) <= RTD_STALE_TIMEOUT_MS;
}

float validateAsyncTemperature(LocalMAX31865 &rtd,uint16_t raw,bool fault,uint8_t code) {
  if (fault || code || raw == 0 || raw >= 32767U || !rtd.configurationMatches() ||
      (rtd.readConfig() & MAX31865_CONFIG_1SHOT)) {
    rtd.clearFault();
    return NAN;
  }
  float value=rtd.calculateTemperature(raw,RNOMINAL,R_REF);
  return !isfinite(value) || value < RTD_MIN_C || value > RTD_MAX_C ? NAN : value;
}

void acceptRtdSample(uint8_t ch,float value) {
  qualifiedOvertemp[ch]=isfinite(value) && value >= overtempThreshold(ch);
  float accepted=NAN;
  if (systemState == STATE_BASELINE || systemState == STATE_STEP_RUNNING) {
    recoveryCount[ch]=0;
    recoveryCandidateC[ch]=NAN;
    if (isfinite(value) && (!isfinite(lastValidRtd[ch]) || fabs(value-lastValidRtd[ch]) <= MAX_RTD_STEP_C))
      accepted=lastValidRtd[ch]=value;
  } else if (isfinite(value)) {
    if (!isfinite(recoveryCandidateC[ch]) || fabs(value-recoveryCandidateC[ch]) > MAX_RTD_STEP_C)
      recoveryCount[ch]=1;
    else if (recoveryCount[ch] < RTD_RECOVERY_SAMPLES) recoveryCount[ch]++;
    recoveryCandidateC[ch]=value;
    if (recoveryCount[ch] >= RTD_RECOVERY_SAMPLES) accepted=lastValidRtd[ch]=value;
  } else {
    recoveryCount[ch]=0;
    recoveryCandidateC[ch]=NAN;
  }
  tempRtd[ch]=accepted;
  rtdSampleCount[ch]++;
  if (isfinite(accepted)) {
    lastRtdSampleMillis[ch]=millis(); // age of valid acquisition, never of a failed attempt
    rtdFailureCount[ch]=0;
  } else {
    if (rtdFailureCount[ch] < 255) rtdFailureCount[ch]++;
    if (channelRequired(ch) && systemState == STATE_BASELINE && !stepCommandArmed)
      resetBaselineWindow();
  }
}

void serviceRTDAcquisition() {
  uint32_t nowUs=micros(), nowMs=millis();
  if (rtdState == 0 && (uint32_t)(nowMs-rtdCycleStartMillis) >= RTD_SAMPLE_INTERVAL_MS) {
    rtdCycleStartMillis=nowMs;
    rtd1.clearFault(); rtd2.clearFault();
    rtd1.enableBias(true); rtd2.enableBias(true);
    rtdStateStartUs=micros(); rtdState=1;
  } else if (rtdState == 1 && (uint32_t)(nowUs-rtdStateStartUs) >= RTD_BIAS_SETTLE_US) {
    rtd1.triggerOneShot(); rtd2.triggerOneShot();
    rtdStateStartUs=micros(); rtdState=2;
  } else if (rtdState == 2 && (uint32_t)(nowUs-rtdStateStartUs) >= RTD_CONVERSION_US) {
    bool f1=false,f2=false;
    uint16_t a=rtd1.readRawRTD(f1,rtdFaultCode[0]), b=rtd2.readRawRTD(f2,rtdFaultCode[1]);
    rtd1.enableBias(false); rtd2.enableBias(false);
    acceptRtdSample(0,validateAsyncTemperature(rtd1,a,f1,rtdFaultCode[0]));
    acceptRtdSample(1,validateAsyncTemperature(rtd2,b,f2,rtdFaultCode[1]));
    rtdState=0;
  }
}

static inline void ssrWriteFromISR(uint8_t ch,bool on) {
  if (on != ssrPhysicalState[ch]) {
    ssrPhysicalState[ch]=on;
    digitalWrite(ch == 0 ? ssrPin_C1 : ssrPin_C2,on ? HIGH : LOW);
  }
}

ISR(TCB2_INT_vect) {
  TCB2.INTFLAGS=TCB_CAPT_bm;
  if (!ssrTimerEnabled) {
    ssrWriteFromISR(0,false); ssrWriteFromISR(1,false);
    ssrWindowTickMs=0;
    return;
  }
  // Both deadlines run independently of foreground LCD/UART/I2C work.
  if (++ssrCommandAgeMs >= SSR_COMMAND_TIMEOUT_MS ||
      (ssrStepApplied && ssrStepElapsedMs >= RUN_DURATION_MS)) {
    if (ssrCommandAgeMs >= SSR_COMMAND_TIMEOUT_MS) ssrCommandTimeout=true;
    else ssrRunComplete=true;
    ssrTimerEnabled=false;
    for (uint8_t ch=0;ch<2;ch++) {
      ssrPendingOnMs[ch]=ssrActiveOnMs[ch]=0;
      ssrWriteFromISR(ch,false);
    }
    return;
  }
  if (ssrWindowTickMs == 0) {
    ssrWindowSequence++;
    for (uint8_t ch=0;ch<2;ch++) {
      ssrActiveOnMs[ch]=ch == TEST_INDEX ? ssrPendingOnMs[ch] : 0;
      ssrHighTicksCurrent[ch]=0;
    }
    if (stepLatchRequested && !ssrStepApplied && ssrActiveOnMs[TEST_INDEX] > 0) {
      // Time zero is recorded in the actual scheduler boundary, before GPIO ON.
      ssrStepStartMillis=millis();
      ssrStepStartSequence=ssrWindowSequence;
      ssrStepElapsedMs=0;
      ssrStepApplied=true;
    }
    for (uint8_t ch=0;ch<2;ch++) ssrWriteFromISR(ch,ssrActiveOnMs[ch] > 0);
  }
  for (uint8_t ch=0;ch<2;ch++) if (ssrPhysicalState[ch]) ssrHighTicksCurrent[ch]++;
  ssrWindowTickMs++;
  for (uint8_t ch=0;ch<2;ch++)
    if (ssrActiveOnMs[ch] < PWM_WINDOW_MS && ssrWindowTickMs >= ssrActiveOnMs[ch]) ssrWriteFromISR(ch,false);
  if (ssrWindowTickMs >= PWM_WINDOW_MS) {
    for (uint8_t ch=0;ch<2;ch++) {
      ssrHighTicksLast[ch]=ssrHighTicksCurrent[ch];
      ssrCommandMsLast[ch]=ssrActiveOnMs[ch];
    }
    ssrCompletedWindowSequence=ssrWindowSequence;
    ssrWindowTickMs=0;
  }
  if (ssrStepApplied) ssrStepElapsedMs++;
}

void configureSsrHardwareTimer() {
  const uint32_t counts=(F_CPU/2UL)/1000UL;
  static_assert(counts >= 1UL && counts <= 65536UL,"TCB2 1 ms count out of range");
  static_assert(PWM_WINDOW_MS == 1000U,"V1.1 requires a 1000 ms SSR window");
  static_assert(BASELINE_WINDOW_SAMPLES >= 2 && BASELINE_WINDOW_SAMPLES <= 120,"Baseline window must be 2..120 samples");
  ATOMIC_BLOCK(ATOMIC_RESTORESTATE) {
    TCB2.CTRLA=0; TCB2.CTRLB=TCB_CNTMODE_INT_gc;
    TCB2.CCMP=(uint16_t)(counts-1UL); TCB2.CNT=0;
    TCB2.INTFLAGS=TCB_CAPT_bm; TCB2.INTCTRL=TCB_CAPT_bm;
    TCB2.CTRLA=TCB_CLKSEL_CLKDIV2_gc|TCB_ENABLE_bm;
  }
}

void stopSsrHardwareWindows() {
  ATOMIC_BLOCK(ATOMIC_RESTORESTATE) {
    ssrTimerEnabled=false; stepLatchRequested=false;
    for (uint8_t ch=0;ch<2;ch++) {
      ssrPendingOnMs[ch]=ssrActiveOnMs[ch]=0;
      ssrHighTicksCurrent[ch]=ssrHighTicksLast[ch]=ssrCommandMsLast[ch]=0;
      ssrPhysicalState[ch]=false;
    }
    digitalWrite(ssrPin_C1,LOW); digitalWrite(ssrPin_C2,LOW);
  }
  completedCommandMs=0; scheduledHighUs=0; scheduledDutyPct=0;
}

void startSsrHardwareWindows() {
  stopSsrHardwareWindows();
  ATOMIC_BLOCK(ATOMIC_RESTORESTATE) {
    ssrWindowSequence=ssrCompletedWindowSequence=0;
    ssrWindowTickMs=ssrCommandAgeMs=0;
    ssrStepApplied=ssrRunComplete=false;
    ssrStepStartMillis=ssrStepStartSequence=ssrStepElapsedMs=0;
    ssrTimerEnabled=true;
  }
  completedWindowSequence=0;
  lastHeartbeatMillis=millis();
}

void snapshotCompletedSsrWindow() {
  uint32_t sequence;
  uint16_t high,command;
  ATOMIC_BLOCK(ATOMIC_RESTORESTATE) {
    sequence=ssrCompletedWindowSequence;
    high=ssrHighTicksLast[TEST_INDEX]; command=ssrCommandMsLast[TEST_INDEX];
  }
  if (sequence == completedWindowSequence) return;
  completedWindowSequence=sequence;
  completedCommandMs=command; scheduledHighUs=(uint32_t)high*1000UL;
  scheduledDutyPct=high*100.0f/PWM_WINDOW_MS;
}
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
void loop() {
  uint32_t nowUs=micros();
  if (lastLoopStartUs) loopMaxUs=max(loopMaxUs,(uint32_t)(nowUs-lastLoopStartUs));
  lastLoopStartUs=nowUs;
  serviceRTDAcquisition(); snapshotCompletedSsrWindow(); serviceStepActivation(); evaluateSafety();
  if (checkButtonPress()) {
    if (systemState == STATE_IDLE) {
      if (!beginBaseline()) Serial.println(F("# EVENT: TEST_START_REJECTED - CHECK CONFIGURATION AND REQUIRED SENSORS"));
    } else if (systemState == STATE_BASELINE || systemState == STATE_STEP_RUNNING) abortRun(F("USER_ABORT"));
    else if (systemState == STATE_ALARM) acknowledgeAlarmIfSafe();
    else {
      stopSsrHardwareWindows(); systemState=STATE_IDLE;
      experimentStartMillis=stepStartMillis=terminalMillis=0; forceLog=true;
      Serial.println(F("# EVENT: RESET_TO_IDLE"));
    }
  }
  serviceBaselineQualification();
  if (systemState == STATE_STEP_RUNNING && ssrRunComplete) {
    stopSsrHardwareWindows(); systemState=STATE_COMPLETE;
    terminalMillis=stepStartMillis+RUN_DURATION_MS; forceLog=true;
    Serial.println(F("# EVENT: RUN_COMPLETE - BOTH_SSR_DISABLED"));
  }
  if (systemState == STATE_ALARM && (uint32_t)(millis()-lastAlarmBeepMillis) >= 300UL) {
    lastAlarmBeepMillis=millis(); alarmBuzzerOn=!alarmBuzzerOn;
    if (alarmBuzzerOn) tone(buzzerPin,2000); else noTone(buzzerPin);
  } else if (systemState != STATE_ALARM && alarmBuzzerOn) { noTone(buzzerPin); alarmBuzzerOn=false; }
  updateLCD();
  if ((uint32_t)(millis()-lastHeaderMillis) >= HEADER_INTERVAL_MS) emitHeader();
  logSerial(); // all states, including repeated machine-readable terminal records
  if ((systemState == STATE_BASELINE || systemState == STATE_STEP_RUNNING) &&
      (uint32_t)(millis()-lastHeartbeatMillis) >= 500UL) {
    ATOMIC_BLOCK(ATOMIC_RESTORESTATE) { if (!ssrCommandTimeout) ssrCommandAgeMs=0; }
    lastHeartbeatMillis=millis();
  }
  wdt_reset(); // serviced only after a complete foreground iteration
}

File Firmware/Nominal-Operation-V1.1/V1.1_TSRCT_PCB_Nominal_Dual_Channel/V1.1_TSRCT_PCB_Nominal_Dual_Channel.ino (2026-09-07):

// V1.1 TSRCT-PCB Nominal Dual-Channel Temperature Controller
// Shipped pair: V1.1_TSRCT_PCB_Nominal_Logger.py (V2 diagnostics retained).
// Board: Arduino Nano Every, Arduino megaAVR Boards core, ATmega4809.
// Library: LiquidCrystal_I2C (Frank de Brabander 1.1.2 API: init/backlight).
// Keep this sketch in a folder named V1.1_TSRCT_PCB_Nominal_Dual_Channel.
// EXPERIMENTAL TEST-BENCH CHECKS PASSED
//
// V1.1: Pt100/430 ohm, independently configurable derivative filters,
// manuscript conditional integration, RTD recovery, command timeout/watchdog,
// safe startup, 50 Hz rejection, and CRC-16 protected telemetry.
// Both channels default to CONTROL. Boot and watchdog reset NEVER arm heating.
// Verify the selected gains, sensor/SSR mapping and fault behaviour on the plant.
// GPIO duty below is scheduler bookkeeping, not an electrical measurement.
// Independent heater thermal fuses remain necessary for a stuck-on SSR.
// Nominal-operation firmware for TSRCT-PCB-01 Rev B / Arduino Nano Every (ATmega4809).
//
// Fixed hardware mapping retained from the validated dual-channel firmware:
//   Channel 1 = RTD1 (CS7) -> independent PID 1 -> SSR A6
//   Channel 2 = RTD2 (CS6) -> independent PID 2 -> SSR A7
//   Software SPI: MOSI D8, MISO D9, SCK D10
//   Push-button D2, buzzer D3, 20x4 I2C LCD at 0x27
//
// Channel modes:
//   CHANNEL_OFF        : RTD acquisition ignored; PID off; SSR forced off; channel faults ignored.
//   CHANNEL_SENSE_ONLY : RTD measurement active; PID off; SSR forced off; RTD/overtemp safety active.
//   CHANNEL_CONTROL    : RTD measurement + PID + SSR actuation active; RTD/overtemp safety active.
//
// Master state machine:
//   SYS_IDLE   : sensing continues for enabled channels; both SSR outputs forced off.
//   SYS_ACTIVE : CONTROL channels run independently; SENSE_ONLY channels remain measurement-only.
//   SYS_ALARM  : latched global alarm; BOTH SSR outputs forced off until the fault clears and
//                the push-button is pressed. Alarm acknowledgement returns to IDLE only.
//
// Safety philosophy:
//   Any active-channel overtemperature, persistent RTD failure, or stale RTD signal disables
//   BOTH heater channels. An OFF channel is intentionally excluded from fault qualification.
//
// Serial telemetry:
//   One D-prefixed row is emitted at 1 Hz continuously (IDLE, ACTIVE and ALARM) for the companion
//   Python logger. Configuration/event lines begin with '#'.

#include <Arduino.h>
#if !defined(__AVR_ATmega4809__)
#error "V1.1 requires an Arduino Nano Every (ATmega4809), not a classic Nano."
#endif
#include <avr/wdt.h>
#include <Wire.h>
#include <LiquidCrystal_I2C.h>
#include <SPI.h>
#include <string.h>
#include <math.h>
#include <avr/interrupt.h>
#include <util/atomic.h>


// ============================================================================
// LOCAL NON-BLOCKING MAX31865 DRIVER
// Derived from the supplied Adafruit MAX31865 implementation (BSD licence).
// ============================================================================
#define MAX31865_CONFIG_REG       0x00
#define MAX31865_CONFIG_BIAS      0x80
#define MAX31865_CONFIG_MODEAUTO  0x40
#define MAX31865_CONFIG_1SHOT     0x20
#define MAX31865_CONFIG_3WIRE     0x10
#define MAX31865_CONFIG_FAULTSTAT 0x02
#define MAX31865_CONFIG_FILT50HZ  0x01
#define MAX31865_RTDMSB_REG       0x01
#define MAX31865_HFAULTMSB_REG    0x03
#define MAX31865_HFAULTLSB_REG    0x04
#define MAX31865_LFAULTMSB_REG    0x05
#define MAX31865_LFAULTLSB_REG    0x06
#define MAX31865_FAULTSTAT_REG    0x07
#define RTD_A 3.9083e-3
#define RTD_B -5.775e-7

typedef enum max31865_numwires {
  MAX31865_2WIRE = 0, MAX31865_3WIRE = 1, MAX31865_4WIRE = 0
} max31865_numwires_t;

class LocalMAX31865 {
 public:
  LocalMAX31865(uint8_t cs, uint8_t mosi, uint8_t miso, uint8_t sck)
      : csPin(cs), mosiPin(mosi), misoPin(miso), sckPin(sck) {}

  bool begin(max31865_numwires_t wires, bool filter50Hz) {
    pinMode(csPin, OUTPUT);
    pinMode(mosiPin, OUTPUT);
    pinMode(misoPin, INPUT);
    pinMode(sckPin, OUTPUT);
    digitalWrite(csPin, HIGH);
    digitalWrite(sckPin, LOW);
    digitalWrite(mosiPin, LOW);

    uint8_t cfg = readRegister8(MAX31865_CONFIG_REG);
    cfg &= ~(MAX31865_CONFIG_BIAS | MAX31865_CONFIG_MODEAUTO |
             MAX31865_CONFIG_1SHOT | MAX31865_CONFIG_FILT50HZ);
    if (wires == MAX31865_3WIRE) cfg |= MAX31865_CONFIG_3WIRE;
    else cfg &= ~MAX31865_CONFIG_3WIRE;
    if (filter50Hz) cfg |= MAX31865_CONFIG_FILT50HZ;
    expectedConfig = cfg & (MAX31865_CONFIG_MODEAUTO | MAX31865_CONFIG_3WIRE |
                            MAX31865_CONFIG_FILT50HZ);
    writeRegister8(MAX31865_CONFIG_REG, cfg);
    setThresholds(0, 0xFFFF);
    clearFault();
    return configurationMatches();
  }

  bool configurationMatches() {
    const uint8_t mask = MAX31865_CONFIG_MODEAUTO | MAX31865_CONFIG_3WIRE |
                         MAX31865_CONFIG_FILT50HZ;
    return (readConfig() & mask) == expectedConfig;
  }

  uint8_t readFault() {
    return readRegister8(MAX31865_FAULTSTAT_REG);
  }

  void clearFault() {
    uint8_t c = readRegister8(MAX31865_CONFIG_REG);
    c &= ~0x2C;
    c |= MAX31865_CONFIG_FAULTSTAT;
    writeRegister8(MAX31865_CONFIG_REG, c);
  }

  void enableBias(bool enabled) {
    uint8_t c = readRegister8(MAX31865_CONFIG_REG);
    if (enabled) c |= MAX31865_CONFIG_BIAS;
    else c &= ~MAX31865_CONFIG_BIAS;
    writeRegister8(MAX31865_CONFIG_REG, c);
  }

  void triggerOneShot() {
    uint8_t c = readRegister8(MAX31865_CONFIG_REG);
    c |= MAX31865_CONFIG_1SHOT;
    writeRegister8(MAX31865_CONFIG_REG, c);
  }

  uint16_t readRawRTD(bool &faultPresent, uint8_t &faultCode) {
    uint16_t r = readRegister16(MAX31865_RTDMSB_REG);
    faultCode = readFault();
    faultPresent = ((r & 1U) != 0U) || (faultCode != 0U);
    return r >> 1;
  }

  float calculateTemperature(uint16_t raw, float nominal, float ref) {
    float Z1, Z2, Z3, Z4, Rt, temp;
    Rt = raw;
    Rt /= 32768.0f;
    Rt *= ref;
    Z1 = -RTD_A;
    Z2 = RTD_A * RTD_A - (4.0f * RTD_B);
    Z3 = (4.0f * RTD_B) / nominal;
    Z4 = 2.0f * RTD_B;
    temp = Z2 + (Z3 * Rt);
    temp = (sqrt(temp) + Z1) / Z4;
    if (temp >= 0.0f) return temp;

    Rt /= nominal;
    Rt *= 100.0f;
    float p = Rt;
    temp = -242.02f;
    temp += 2.2228f * p;
    p *= Rt; temp += 2.5859e-3f * p;
    p *= Rt; temp -= 4.8260e-6f * p;
    p *= Rt; temp -= 2.8183e-8f * p;
    p *= Rt; temp += 1.5243e-10f * p;
    return temp;
  }

  uint8_t readConfig() {
    return readRegister8(MAX31865_CONFIG_REG);
  }

 private:
  uint8_t csPin, mosiPin, misoPin, sckPin;
  uint8_t expectedConfig = 0;

  uint8_t transfer8(uint8_t out) {
    uint8_t in = 0;
    for (uint8_t m = 0x80; m; m >>= 1) {
      digitalWrite(mosiPin, (out & m) ? HIGH : LOW);
      digitalWrite(sckPin, HIGH);
      delayMicroseconds(1);
      digitalWrite(sckPin, LOW);
      if (digitalRead(misoPin)) in |= m;
      delayMicroseconds(1);
    }
    return in;
  }
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

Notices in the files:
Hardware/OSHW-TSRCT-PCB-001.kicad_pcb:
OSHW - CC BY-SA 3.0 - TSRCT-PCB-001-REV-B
